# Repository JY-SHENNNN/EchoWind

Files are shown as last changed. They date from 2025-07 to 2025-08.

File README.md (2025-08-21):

# 🌬️ EchoWind: A Connected System for Wind Sensing and Sonified Feedback

This project explores how **real-time wind data** can be translated into **sound** through two interactive physical devices — a **vibration-driven wind chime** and a **servo-controlled xylophone**.  
The system aims to **enhance environmental perception** and foster **biophilic interaction** in architectural spaces.

<div align="center">
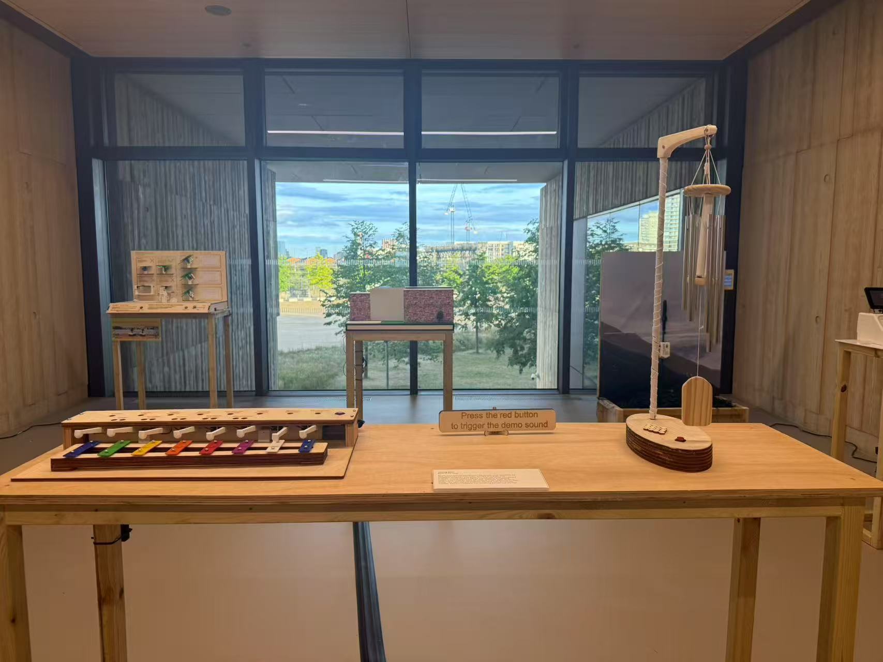
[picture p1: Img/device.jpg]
  
</div>

---

## 🎯 Background & Motivation
Humans in indoor environments have limited perception of natural wind.  
EchoWind bridges this sensory gap by **sonifying wind speed** detected near the building, creating a tangible connection between **outdoor natural phenomena** and **indoor experiences**.  
The project draws inspiration from *biophilic design* principles and aims to provide:  
- **Sensory enrichment** in architectural spaces  
- **Ambient awareness** of changing weather  
- **Interactive art installations** for museums or public spaces  

---

## 🎥 Demo

https://github.com/user-attachments/assets/2d0ca31f-c91a-428a-b187-3b79d9365f25
<div align=center>
  <p><strong>Demo 1.</strong> Anemometer</p>
</div>

https://github.com/user-attachments/assets/f828534c-1641-437a-8894-df54421aac83
<div align=center>
  <p><strong>Demo 2.</strong> Wind Chimes</p>
</div>

https://github.com/user-attachments/assets/cbe92d59-73f2-4cc1-957b-6b1370a6ae0b
<div align=center>
  <p><strong>Demo 3.</strong> Xylophone </p>
</div>

---

## 📡 System Overview

- **Sensor Node**: An anemometer measures wind speed and publishes real-time data to an MQTT broker.
- **Actuator Nodes**: Two microcontrollers subscribe to the wind topic and sonify the data:
  - 🎐 **Wind Chime** — Vibration motor strikes metal tubes based on wind intensity.
  - 🎹 **Xylophone** — 8× MG90S servos hit keys mapped to wind levels.

<div align=center>
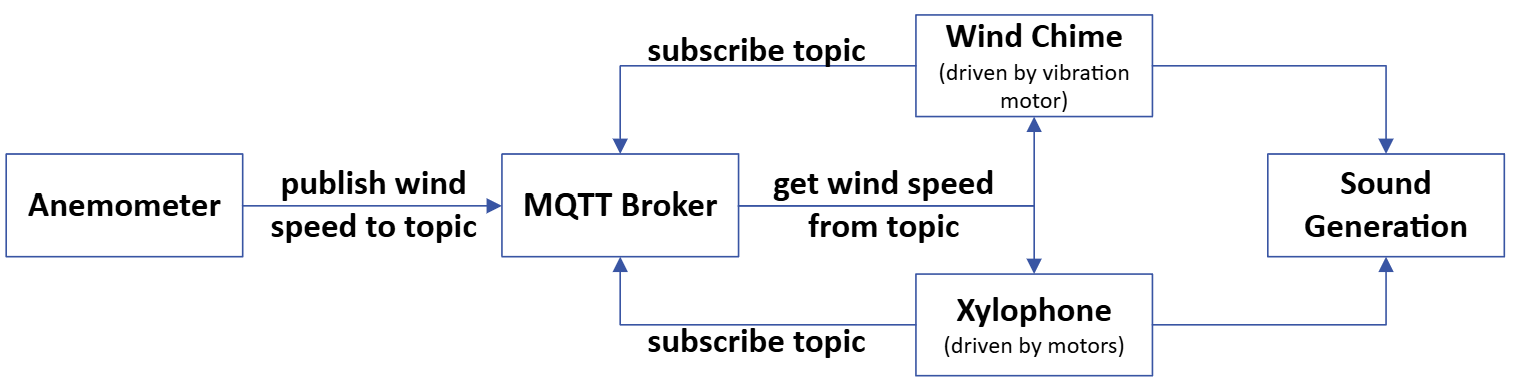
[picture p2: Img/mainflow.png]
  
  <p><strong>Fig. 1.</strong> System Overview</p>
</div>

---

## ⚙️ Hardware
| Component | Description |
|---|---|
| **Anemometer** | Wind speed sensor (0–70 m/s), placed in an open-door area |
| **Wind Chime** | Arduino MKR1010 + MOSFET-driven vibration motor |
| **Xylophone** | ESP32-C6 Feather board + 8× MG90S servos |
| **Power Supply** | Three 5V 2A USB adapters (optional lithium battery backup) |

---

## 🔌 Circuit Diagrams
**Sensor Node**  
<div align=center>
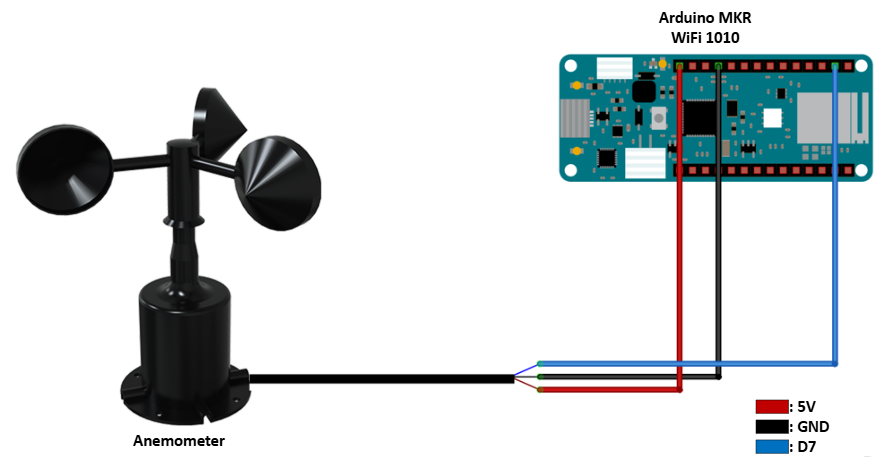
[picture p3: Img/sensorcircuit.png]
    
    <p><strong>Fig. 2.</strong> Circuit diagram for the sensor node.</p>
</div>

**Wind Chime**  
<div align=center>
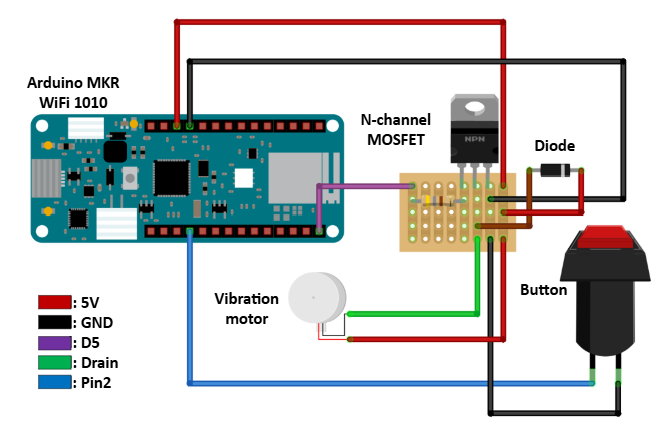
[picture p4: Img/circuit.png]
    
    <p><strong>Fig. 3.</strong> Circuit diagram for the wind chime node.</p>
</div>

**Xylophone**  
<div align=center>
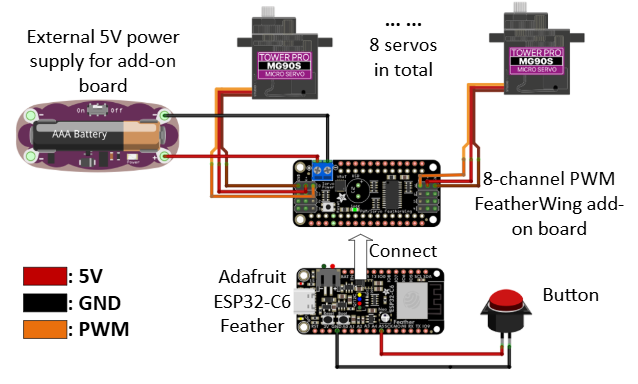
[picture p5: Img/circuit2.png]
    
    <p><strong>Fig. 4.</strong> Circuit diagram for the xylophone node.</p>
</div>

---

## 🛠 Installation & Setup

### 1️⃣ Hardware Assembly
- **Anemometer:** Connect the anemometer to the Arduino MKR1010 as shown in the diagrams above.
- **Wind Chime:** Attach vibration motor for wind chime to the MKR1010 and connect to the 5V power supply.

- **Xylophone:** Connect the ESP32-C6 Feather board to the 5V power supply and connect the MG90S servos to the ESP32-C6 Add-on board with external power supply.
### 2️⃣ Software Requirements
- Arduino IDE or PlatformIO  
- Libraries:  
  - `PubSubClient.h` (MQTT)  
  - `WiFiNINA.h` (for EMKR1010)  
  - `Adafruit_PWMServoDriver.h` (for MG90S control)  
  - `WiFi.h` (for ESP32-C6)
  - `esp_system.h` (for ESP32-C6)
  - `esp_system.h` (for ESP32-C6)
  - `esp_sleep.h`
  - include `arduino_secrets.h` file for WiFi credentials and MQTT broker details.
### 3️⃣ Code Implementation
The `Code` directory contains the following Arduino sketches: All sketches except `servoCalibrate.ino` require the `arduino_secrets.h` file to be present in the same directory.

- `sensor.ino`  
  Program for the **anemometer node**.

- `Windchime.ino`  
  Program for the **wind chime node**.

- `Glockenspiel.ino`  
  Program for the **xylophone node**.

- `servoCalibrate.ino`  
  Utility sketch for calibrating the **xylophone servos**.

### 4️⃣ Enclosure Design
The `src` directory contains the following 3D-printable STL files:

- `anemometer.stl` and `anemometerbottom.stl`  
  Enclosure parts for the anemometer (can be printed using Fusion 360 or other CAD software).  

- `chimetube.stl`  
  Central wire cover for the wind chime.  

- `holder.stl`  
  Servo holder.  

- `mallet.stl`  
  Xylophone mallet for striking.  

--- 
 ## Package
 ```
1. https://forum.fritzing.org/t/anemometer-in-fritzing/12799/2
2. https://github.com/adafruit/Fritzing-Library
3. https://github.com/johnyHV/fritzing-parts/blob/master/Servo%20MG90S.fzpz
 ```
---
## Reference
https://www.rkonfly.cn/index.php/index/shows/catid/42/id/95.html

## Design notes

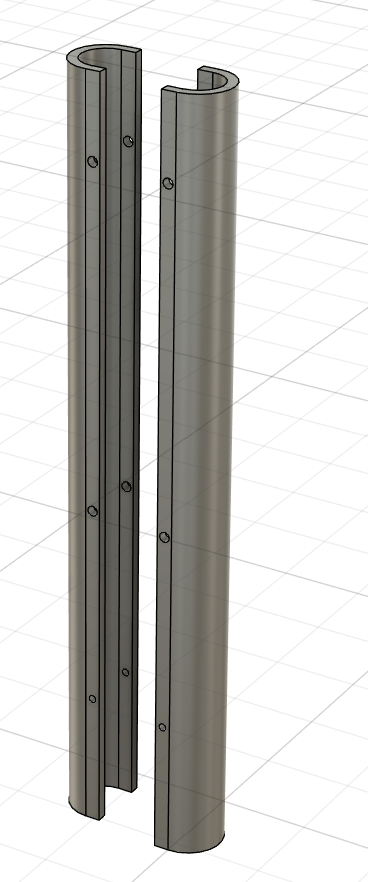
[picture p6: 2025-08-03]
Img/tube.png

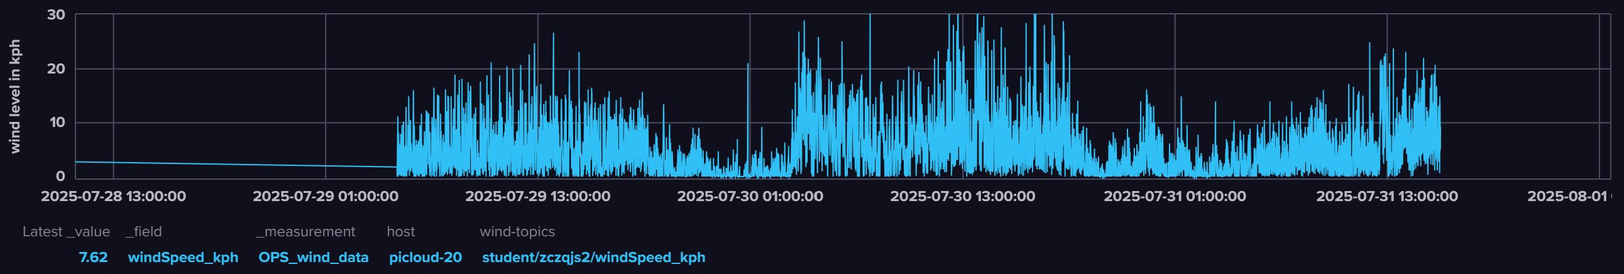
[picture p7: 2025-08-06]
Img/seconddata.png

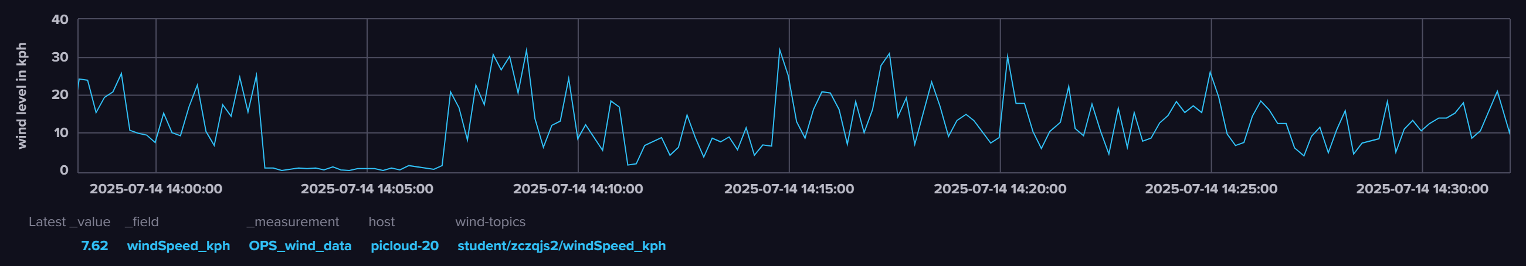
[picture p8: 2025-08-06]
Img/firstday.png

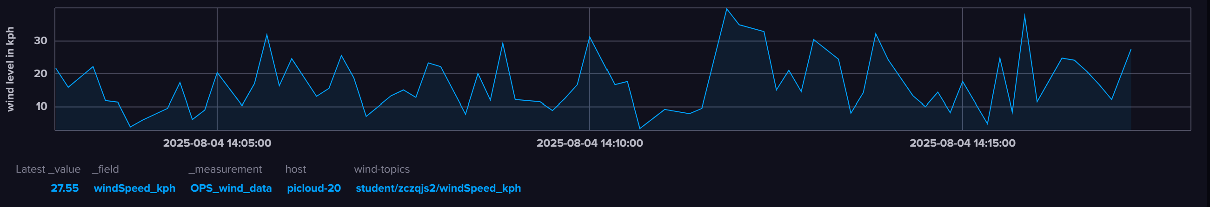
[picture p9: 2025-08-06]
Img/new.png

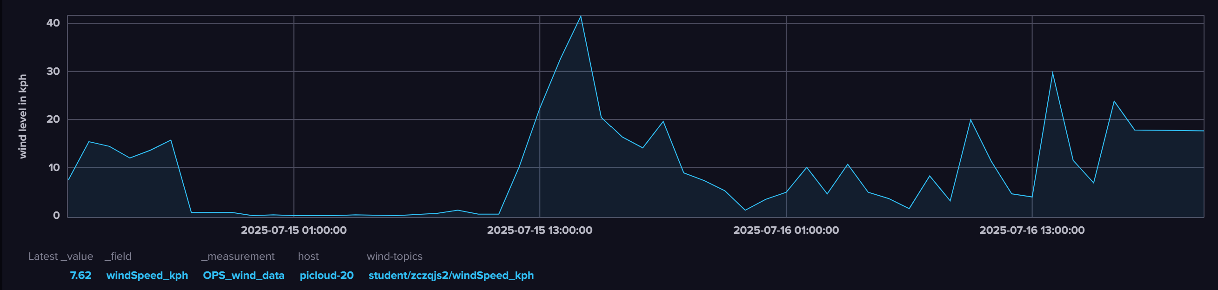
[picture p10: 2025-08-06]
Img/valueinfirstweek.png

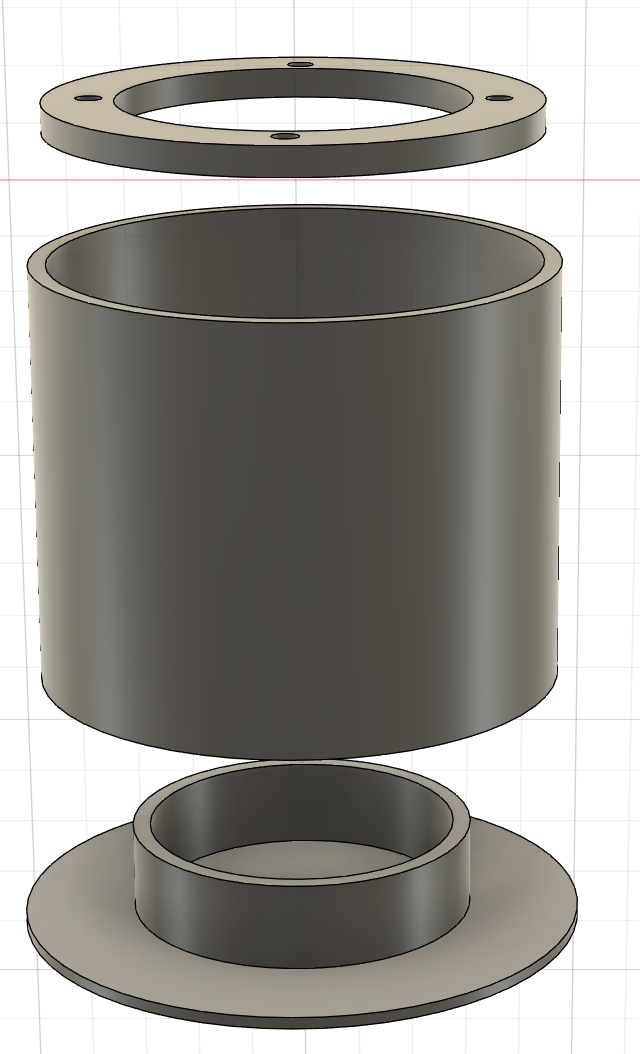
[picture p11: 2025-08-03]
Img/sensorEnclo.png

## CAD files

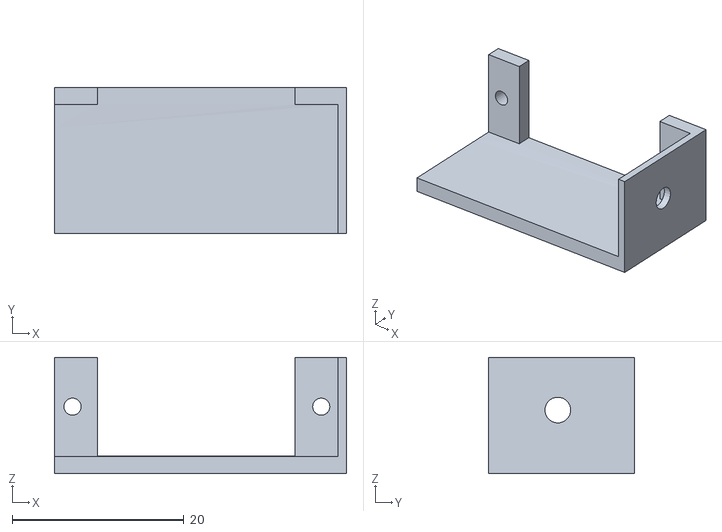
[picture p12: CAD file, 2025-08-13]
src/holder.stl
34.0 x 17.0 x 13.5

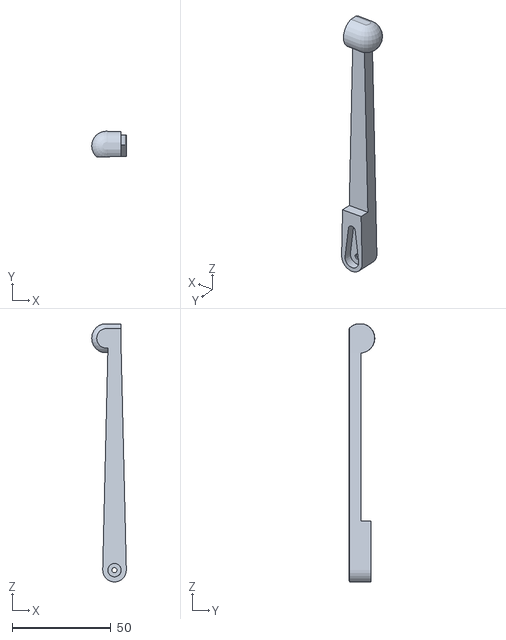
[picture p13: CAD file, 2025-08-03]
src/mallet.stl
17.6 x 13.1 x 130.7

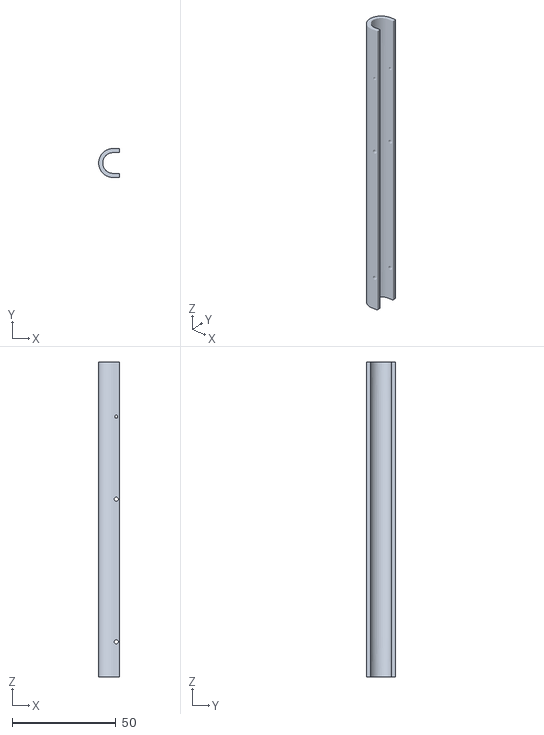
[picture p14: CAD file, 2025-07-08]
src/chimetube.stl
10.0 x 14.0 x 152.0

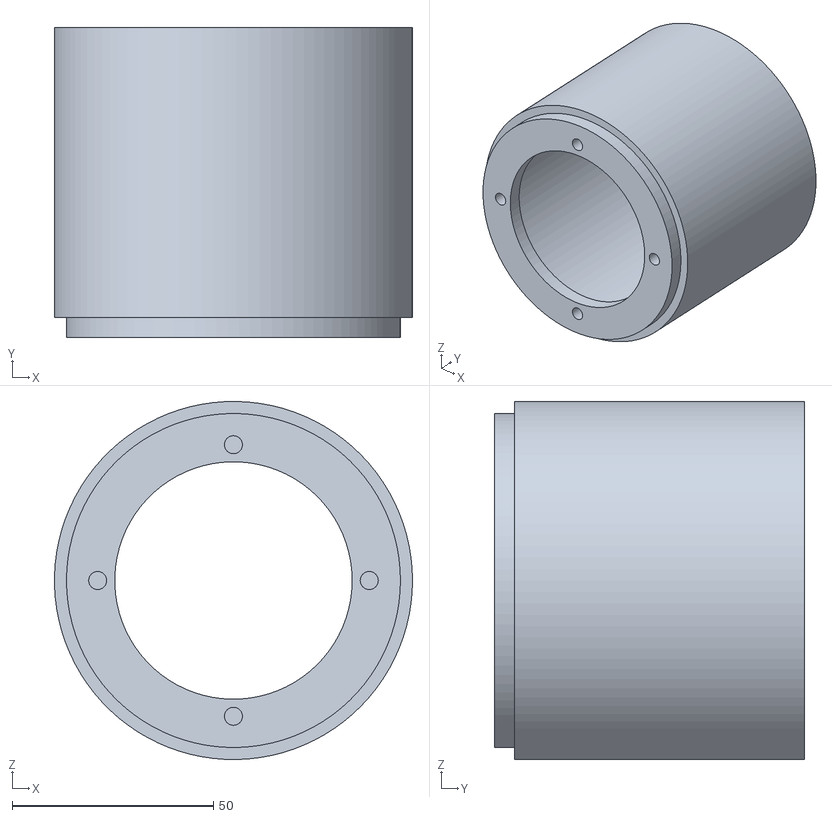
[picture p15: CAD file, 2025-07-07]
src/anemometer.stl
89.0 x 77.1 x 89.0

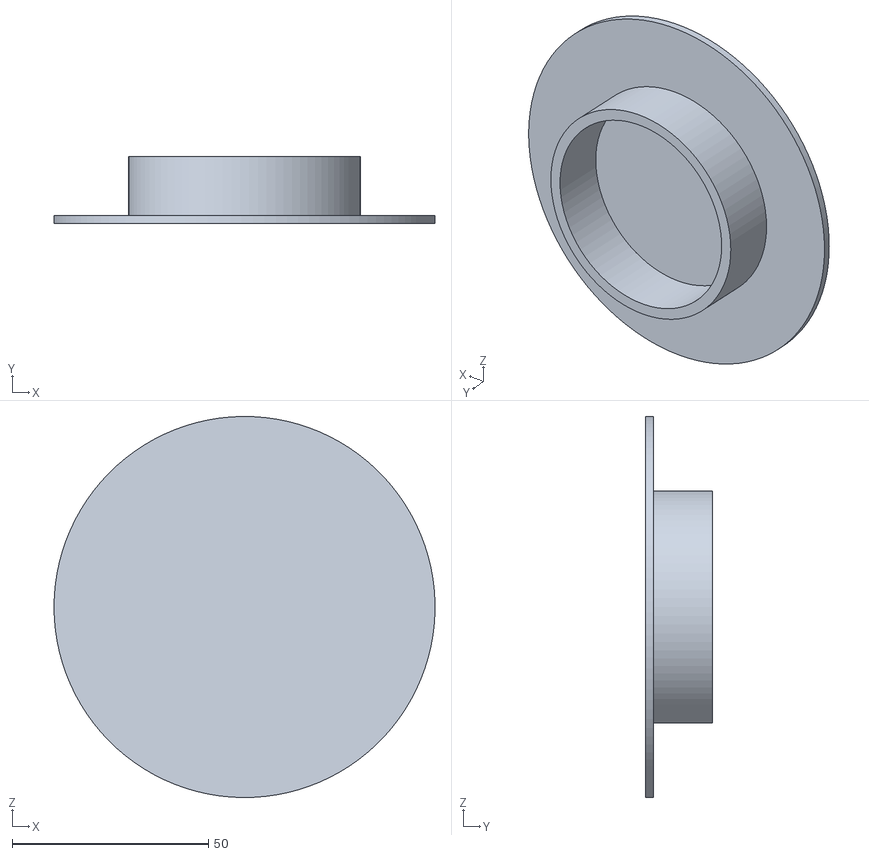
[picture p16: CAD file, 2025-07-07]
src/anemometerbottom.stl
97.0 x 17.0 x 97.0

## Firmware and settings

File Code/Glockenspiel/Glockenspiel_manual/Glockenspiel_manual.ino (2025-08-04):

#include <WiFi.h>
#include <PubSubClient.h>
#include "arduino_secrets.h"
#include <Adafruit_PWMServoDriver.h>
#include "esp_system.h"
#include "esp_sleep.h"

#define SERVO_FREQ 50
#define NUM_SERVOS 8
#define button_pin 5

const char* ssid = SECRET_SSID;
const char* password = SECRET_PASS;

const char* mqtt_server = "mqtt.cetools.org";
const int mqtt_port = 1884;
const char* mqtt_user = SECRET_MQTTUSER;
const char* mqtt_pass = SECRET_MQTTPASS;
const char* mqtt_topic = "student/zczqjs2/windSpeed_kph";

WiFiClient espClient;
PubSubClient client(espClient);
Adafruit_PWMServoDriver pwm = Adafruit_PWMServoDriver();

float messageHistory[8];
int messageIndex = 0;
bool collectingData = false;

bool lastButtonState = HIGH;
bool currentButtonState = HIGH;
unsigned long lastDebounceTime = 0;
const unsigned long debounceDelay = 50;

String lastMessage = "";

int strikePositions[NUM_SERVOS] = {
  2100, 2100, 2150, 2200, 2100, 2150, 1980, 1980
};

// origin
int restPositions[NUM_SERVOS] = {
  1930, 1900, 1900, 1900, 1920, 1930, 1900, 1870
};

void connectToWiFiWithTimeout() {
  WiFi.begin(ssid, password);
  Serial.print("Connecting to WiFi");
  unsigned long startTime = millis();
  while (WiFi.status() != WL_CONNECTED && millis() - startTime < 15000) {
    delay(500);
    Serial.print(".");
  }
  if (WiFi.status() == WL_CONNECTED) {
    Serial.println("\nWiFi connected!");
    Serial.println(WiFi.localIP());
  } else {
    Serial.println("\nWiFi failed. Restarting ESP32...");
    esp_restart();
  }
}

void connectToMQTT() {
  while (!client.connected()) {
    Serial.print("Connecting to MQTT...");
    if (client.connect("ESP32Client", mqtt_user, mqtt_pass)) {
      Serial.println("connected");
      client.subscribe(mqtt_topic);
    } else {
      Serial.print("failed, rc=");
      Serial.print(client.state());
      Serial.println(" try again in 5 seconds");
      delay(5000);
    }
  }
}

void callback(char* topic, byte* message, unsigned int length) {
  String currentMessage = "";
  for (int i = 0; i < length; i++) {
    currentMessage += (char)message[i];
  }

  if (collectingData && messageIndex < 8) {
    float ms = currentMessage.toFloat();
    messageHistory[messageIndex] = ms;
    messageIndex++;

    Serial.print("Collected [");
    Serial.print(messageIndex);
    Serial.print("/8] wind speed: ");
    Serial.println(ms);
  }

  lastMessage = currentMessage;
}

int mapToBeaufort(float ms) {
  if (ms < 0.2) return 0;
  else if (ms <= 1.5) return 1;
  else if (ms <= 3.3) return 2;
  else if (ms <= 5.4) return 3;
  else if (ms <= 7.9) return 4;
  else if (ms <= 10.7) return 5;
  else if (ms <= 13.8) return 6;
  else if (ms <= 17.1) return 7;
  else if (ms <= 20.7) return 8;
  else if (ms <= 24.4) return 9;
  else if (ms <= 28.4) return 10;
  else if (ms <= 32.6) return 11;
  else return 12;
}

void playSingleBeaufort(int level) {
  if (level > 7) {
    pwm.writeMicroseconds(level - 8, strikePositions[level - 8]);
    delay(40);
    pwm.writeMicroseconds(level - 8, restPositions[level - 8]);
    delay(500);
    pwm.writeMicroseconds(level - 7, strikePositions[level - 7]);
    delay(40);
    pwm.writeMicroseconds(level - 7, restPositions[level - 7]);
    delay(1000);
  } else {
    pwm.writeMicroseconds(level, strikePositions[level]);
    delay(40);
    pwm.writeMicroseconds(level, restPositions[level]);
    delay(1000);
  }
}

void playCollectedChime() {
  Serial.println(" Playing collected chime data for 20 seconds...");

  unsigned long startTime = millis();

  while (millis() - startTime < 20000) {  // play 20 seconds
    for (int i = 0; i < 8; i++) {
      int level = mapToBeaufort(messageHistory[i]);
      Serial.print("Data ");
      Serial.print(i + 1);
      Serial.print(": ");
      Serial.print(messageHistory[i]);
      Serial.print(" m/s → Beaufort ");
      Serial.println(level);

      playSingleBeaufort(level);
      client.loop();  // ensure MQTT connection
    }
  }

  Serial.println("20s wind chime playback complete.");
}


void setup() {
  Serial.begin(115200);
  delay(1000);
  pinMode(button_pin, INPUT_PULLUP);

  connectToWiFiWithTimeout();

  pwm.begin();
  pwm.setOscillatorFrequency(27000000);
  pwm.setPWMFreq(SERVO_FREQ);
  delay(10);
  for (int i = 0; i < NUM_SERVOS; i++) {
    pwm.writeMicroseconds(i, restPositions[i]);
  }

  client.setServer(mqtt_server, mqtt_port);
  client.setCallback(callback);
  connectToMQTT();
  esp_sleep_enable_ext1_wakeup(1ULL << GPIO_NUM_5, ESP_EXT1_WAKEUP_ALL_LOW);

}

void loop() {
  if (WiFi.status() != WL_CONNECTED) {
    connectToWiFiWithTimeout();
    delay(1000);
  }
  if (!client.connected()) {
    connectToMQTT();
  }

  client.loop();

  int reading = digitalRead(button_pin);

  if (reading != currentButtonState) {
    lastDebounceTime = millis();
    currentButtonState = reading;
  }

  if ((millis() - lastDebounceTime) > debounceDelay) {
    if (digitalRead(button_pin) == LOW) {
      //lastButtonState = currentButtonState;

      Serial.println("Button state changed → start collecting 8 wind speeds");

      // Reset state
      messageIndex = 0;
      collectingData = true;
      int toneIndex = 0;

      // Loop: wait for 8 MQTT values while playing tones 0–7
      while (messageIndex < 8) {
        client.loop();  // keep MQTT alive
        pwm.writeMicroseconds(toneIndex, strikePositions[toneIndex]);
        delay(40);
        pwm.writeMicroseconds(toneIndex, restPositions[toneIndex]);
        delay(5000);
        // playSingleBeaufort(toneIndex);
        toneIndex = (toneIndex + 1) % 8;
      }

      collectingData = false;
      Serial.println("Data collection done. Now playing actual tones...");
      playCollectedChime();
      delay(1000);
      esp_deep_sleep_start();

    }
  }
}

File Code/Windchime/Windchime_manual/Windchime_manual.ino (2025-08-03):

#include <WiFiNINA.h>
#include <PubSubClient.h>
#include "arduino_secrets.h"

#define motor_pin 5
#define button_pin 2  //added button

const char* ssid          = SECRET_SSID;
const char* password      = SECRET_PASS;
const char* mqtt_username = SECRET_MQTTUSER;
const char* mqtt_password = SECRET_MQTTPASS;

const char* mqtt_server = "mqtt.cetools.org";
const int mqtt_port = 1884;
//const char* mqtt_topic = "UCL/OPS/Garden/WST/dvp2/windSpeed_kph";
const char* mqtt_topic = "student/zczqjs2/windSpeed_kph";
WiFiClient wifiClient;
PubSubClient client(wifiClient);

String lastMessage = "";
float speed_kph;
bool messageChanged = false;
bool enableMotor = false;

bool lastButtonState = HIGH;         //（INPUT_PULLUP）
bool currentButtonState;
unsigned long lastDebounceTime = 0;
const unsigned long debounceDelay = 50;

void connectToWiFiWithTimeout() {
  WiFi.begin(ssid, password);
  Serial.print("Connecting to WiFi");
  unsigned long startAttemptTime = millis();

  while (WiFi.status() != WL_CONNECTED && millis() - startAttemptTime < 15000) {
    delay(500);
    Serial.print(".");
  }

  if (WiFi.status() == WL_CONNECTED) {
    Serial.println("\nWiFi connected!");
    Serial.print("IP: ");
    Serial.println(WiFi.localIP());
  } else {
    Serial.println("\nWiFi connection failed. Restarting...");
    NVIC_SystemReset();  // restart to connect
  }
}

void reconnectMQTT() {
  while (!client.connected()) {
    Serial.print("Attempting to connect to MQTT broker...");
    if (client.connect("MKR1010_Client", mqtt_username, mqtt_password)) {
      Serial.println("Connected successfully!");
      if (client.subscribe(mqtt_topic)) {
        Serial.println("Successfully subscribed to topic!");
      } else {
        Serial.println("Failed to subscribe!");
      }
    } else {
      Serial.print("Connection failed, error code: ");
      Serial.print(client.state());
      Serial.println(". Retrying in 5 seconds...");
      delay(5000);
    }
  }
}

void callback(char* topic, byte* payload, unsigned int length) {
  String currentMessage = "";
  for (int i = 0; i < length; i++) {
    currentMessage += (char)payload[i];
  }

  if (currentMessage != lastMessage) {
    messageChanged = true;
    Serial.print("Message received from topic [");
    Serial.print(topic);
    Serial.print("]: ");
    Serial.println(currentMessage);
  }

  speed_kph = currentMessage.toFloat();
  lastMessage = currentMessage;
}

void PWMWave() {
  int pwmValue = getPwmValue(speed_kph * 3.6 );
  analogWrite(motor_pin, pwmValue);
  Serial.println(pwmValue);
  delay(5000);
  analogWrite(motor_pin, LOW);
  delay(500);
}

// int getPwmValue(float kph) {
//   if (kph < 1) return map(kph, 0, 1, 0, 10);
//   else if (kph < 5) return map(kph, 1, 5, 10, 30);
//   else if (kph < 11) return map(kph, 5, 11, 30, 80);
//   else if (kph < 19) return map(kph, 11, 19, 80, 120);
//   else if (kph < 28) return map(kph, 19, 28, 120, 180);
//   else return map(kph, 28, 50, 180, 255);
// }

int getPwmValue(float ms) {
  if (ms < 3.3) return map(ms, 0, 3.3, 0, 51);
  else if (ms < 10.7) return map(ms, 3.3, 10.7, 51, 102);
  else if (ms < 20.7) return map(ms, 10.7, 20.7, 102, 153);
  else if (ms < 32.6) return map(ms, 20.7, 32.6, 153, 204);
  else return map(ms, 32.6, 50, 204, 255);
}

void setup() {
  Serial.begin(9600);
  delay(1000);
  pinMode(motor_pin, OUTPUT);
  pinMode(button_pin, INPUT_PULLUP);  // new added pull up resister

  connectToWiFiWithTimeout();

  client.setServer(mqtt_server, mqtt_port);
  client.setCallback(callback);
}

void loop() {
  if (WiFi.status() != WL_CONNECTED) {
    connectToWiFiWithTimeout();
    delay(1000);
  }
  if (!client.connected()) {
    reconnectMQTT();
  }
  client.loop();

  int reading = digitalRead(button_pin);

  // 防抖处理
  if (reading != lastButtonState) {
    lastDebounceTime = millis();
  }

  if ((millis() - lastDebounceTime) > debounceDelay) {
    if (reading != currentButtonState) {
      currentButtonState = reading;
      // button state changed, trigger
      Serial.println("Button state changed. Triggering wind chime.");
      Serial.print("Using last received wind speed: ");
      Serial.println(lastMessage);
      PWMWave();  //anable motor
    }
  }

  lastButtonState = reading;  // update state
}

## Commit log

2025-05-16 first prototype
2025-05-16 add electronic circuit graph
2025-05-27 glockenspiel servo test
2025-06-18 coding for sensor
2025-06-19 wifi check for feather esp32
2025-06-21 forward MQTT sub with servo function
2025-07-02 sound sensor
2025-07-03 calibration for all servos
2025-07-08 new adjustment towards 3d model
    [chimetube.gcode.3mf, chimetube.stl]
2025-07-08 button added on windchime
2025-07-16 button trigger
2025-08-03 iteration of glockenspiel arm
    [02.stl, 123123(1).stl, GLOCK3.stl]
2025-08-06 reorganise resource
    [02.stl, GLOCK3.stl, chimetube.gcode.3mf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]
